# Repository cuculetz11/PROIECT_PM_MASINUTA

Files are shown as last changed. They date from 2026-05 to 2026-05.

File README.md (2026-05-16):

# Land Buster — Autonomous & Multi-Mode Bluetooth Rover

Cucu Viorel-Cosmin 334CA

> **GitHub:** [https://github.com/cuculetz11/PROIECT_PM_MASINUTA](https://github.com/cuculetz11/PROIECT_PM_MASINUTA)  
> **MCU:** ATmega328P Xplained Mini · PlatformIO

---

## Introduction

**Land Buster** is a small RC car (1/12 scale Land Buster chassis) that I upgraded into a smart rover. Instead of using a standard radio remote, I control it from my phone via Bluetooth.

The main idea was simple: a normal RC car does whatever you tell it, even if it is about to crash. I wanted to fix that. So I added sensors and automatic logic on top of the manual control.

**What it does:**
- You drive it with a phone app over Bluetooth. You can pick between 3 speed modes and honk the horn.
- The front ultrasonic sensor watches for obstacles. The buzzer starts beeping faster as you get closer. If you get too close (under 15 cm), the car stops by itself — you cannot override it.
- The headlights turn on automatically when it gets dark, based on a light sensor.
- The LCD screen shows the current speed mode and the distance to the nearest obstacle in real time.

**Why it is useful:** It shows how a cheap microcontroller can handle multiple real-time tasks at once — wireless communication, sensing, motor control, and display — using only hardware registers and no external libraries.

**Course requirements met:**
- **5 laboratory concepts:** USART (Lab 1), Timers & Interrupts (Lab 2), PWM (Lab 3), ADC (Lab 4), I2C (Lab 6)
- **5 external peripherals:** HC-05 Bluetooth, HC-SR04 Ultrasonic, 1602 I2C LCD, Photoresistor, Active Buzzer

---

## General Description

The ATmega328P is the brain of the system. Everything connects to it.

- **Inputs:** Bluetooth commands from the phone, distance data from the ultrasonic sensor, light level from the photoresistor.
- **Processing:** The MCU reads all inputs, decides what to do (drive, stop, beep, light up), and sends signals to the outputs.
- **Outputs:** The ESC drives the main motor (speed), the L298N drives the steering motor (direction), the LCD shows status, the buzzer gives audio alerts, and the LEDs provide lighting.

### Block Diagram

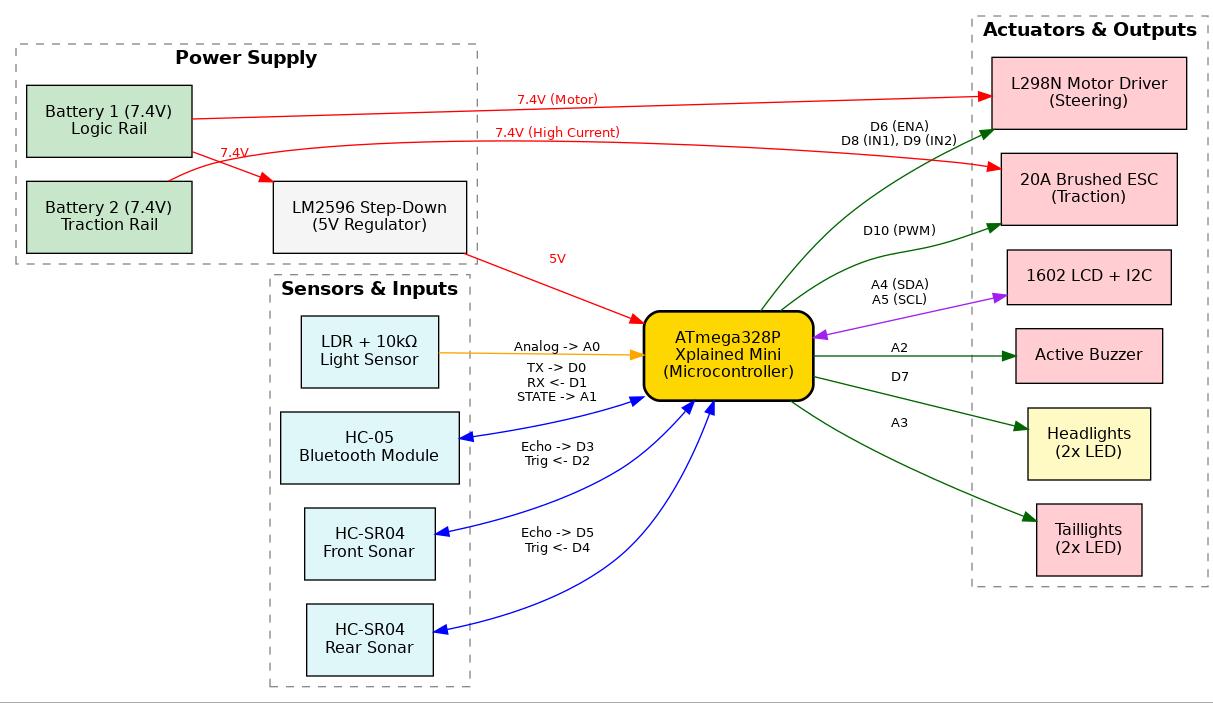
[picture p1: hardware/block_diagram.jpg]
Land Buster System Block Diagram


---

## Hardware Design

### Components and Their Role

| Component | Model | Role in Project |
|---|---|---|
| Microcontroller | ATmega328P Xplained Mini | Central brain. Reads all sensors, runs non-blocking logic, outputs PWM and I2C signals. |
| Bluetooth Module | HC-05 | Bidirectional telemetry with Android app - receives drive commands, sends sensor data. |
| Front Ultrasonic Sensor | HC-SR04 | Measures distance to obstacles ahead. Triggers buzzer alerts and emergency stop at <15 cm. |
| Rear Ultrasonic Sensor | HC-SR04 | Measures distance behind the rover. Powers the reverse parking assist display on the LCD. |
| Light Sensor | GL5528 Photoresistor + 10kΩ | Voltage divider read by ADC. Activates headlights automatically when ambient light drops. |
| Speed Controller | 20A Brushed ESC | Controls the rear 390 DC traction motor via 50 Hz PWM. Receives signal from MCU Timer 1. |
| Traction Motor | 390 DC Motor (7.4V) | Drives the rover forward and backward from Battery 2's dedicated high-current rail. |
| Steering Motor | 3–6V DC Motor | Turns the front axle left or right under L298N control. |
| Motor Driver | L298N H-Bridge | Accepts PWM (ENA) and two direction pins (IN1/IN2) to drive the steering DC motor. |
| LCD Display | 1602 LCD + PCF8574 I2C | "Smart dashboard": shows expressive animated eyes in normal mode, parking assist in reverse. |
| Active Buzzer | TMB12A05 5V | Proximity alert (beep rate increases near obstacles) and horn command from phone. |
| Headlights & Taillights | 5mm LEDs x4 + 220Ω x4 | Front lighting (D7) activates automatically via LDR. Rear taillights (A3) activate on brake/reverse. Wired in parallel. |
| Voltage Regulator | LM2596 Step-Down | Converts Battery 1's 7.4V down to a stable 5V for all logic (MCU, sensors, LCD). |
| Battery 1 - Logic Rail | 2x Murata US18650VTC5C in series | 7.4V, 2600 mAh, 30A. Powers L298N and LM2596 (which feeds 5V logic). |
| Battery 2 - Traction Rail | 2x Samsung 25R 18650 in series | 7.4V, 2500 mAh, 8C. Dedicated high-current supply exclusively for the ESC. |
| Chassis | Land Buster 1/12 scale | Physical base of the rover. |

### Pin Mapping and Justification

| Arduino Pin | AVR Register | Timer / Peripheral | Connected To | Why This Pin |
|---|---|---|---|---|
| D0 (RX) | PD0 | USART0 RX | HC-05 TX | Hardware USART - zero-latency interrupt-driven reception (RXCIE0). No bit-banging needed. |
| D1 (TX) | PD1 | USART0 TX | HC-05 RX via 1kΩ/2kΩ divider | Same USART peripheral. 5V output is divided to 3.3V to protect HC-05 RX logic level. |
| D2 | PD2 | GPIO Output | HC-SR04 Front - TRIG | Any GPIO works for the 10 µs trigger pulse. D2 keeps sensor pins grouped together. |
| D3 | PD3 | GPIO Input | HC-SR04 Front - ECHO | Paired with D2 for clean wiring. Reads echo pulse duration via pulseIn(). |
| D4 | PD4 | GPIO Output | HC-SR04 Rear - TRIG | Same reason as D2; rear sensor pins grouped on D4/D5. |
| D5 | PD5 | GPIO Input | HC-SR04 Rear - ECHO | Paired with D4. Mirrors front sensor logic for parking assist. |
| D6 | PD6 | Timer 0, OC0A (Fast PWM) | L298N ENA | Only OC0A or OC0B can output Timer 0 PWM. D6 = OC0A - sets steering motor duty cycle (0–255). |
| D7 | PD7 | GPIO Output | Headlight LEDs + 220Ω | Simple digital ON/OFF for the LED array. D7 is free from any timer to avoid conflicts. |
| D8 | PB0 | GPIO Output | L298N IN1 | Direction bit for steering H-bridge. No special hardware needed - plain digital output. |
| D9 | PB1 | GPIO Output | L298N IN2 | Direction bit for steering H-bridge (opposite of IN1 to select left/right). |
| D10 | PB2 | Timer 1, OC1B (Phase-correct PWM) | ESC Signal | Timer 1 is 16-bit - essential for generating the precise 50 Hz (20 ms period) servo-style PWM the ESC requires. ICR1=39999, OCR1B range 2600–3400 for speed control. |
| A0 | PC0 | ADC0 | LDR Voltage Divider | First ADC channel; no mux change needed for single-channel reads. Direct analog measurement of light level. |
| A1 | PC1 | GPIO Input | HC-05 STATE | Reads hardware connection status (HIGH = connected, LOW = disconnected/searching). |
| A2 | PC2 | GPIO Output | Active Buzzer | Moved here from SPI pins to keep PB3/PB4/PB5 free for the Xplained Mini's programming interface (EDBG). |
| A3 | PC3 | GPIO Output | Rear LED Taillights | Dedicated pin for red rear taillights. Activates independently during AEB, reverse, or stop. |
| A4 | PC4 | TWI SDA (Hardware I2C) | LCD PCF8574 SDA | Hardware I2C peripheral - only PC4/PC5 support hardware TWI on ATmega328P. |
| A5 | PC5 | TWI SCL (Hardware I2C) | LCD PCF8574 SCL | Paired with A4. Hardware TWI runs at 100 kHz without CPU intervention. |

**Note — SPI pins reserved:** PB3 (MOSI), PB4 (MISO), PB5 (SCK) are left unconnected. These are used internally by the Xplained Mini's on-board EDBG debugger for programming. Connecting peripherals to them would block firmware uploads.

### Key Design Choices & Electrical Schematic

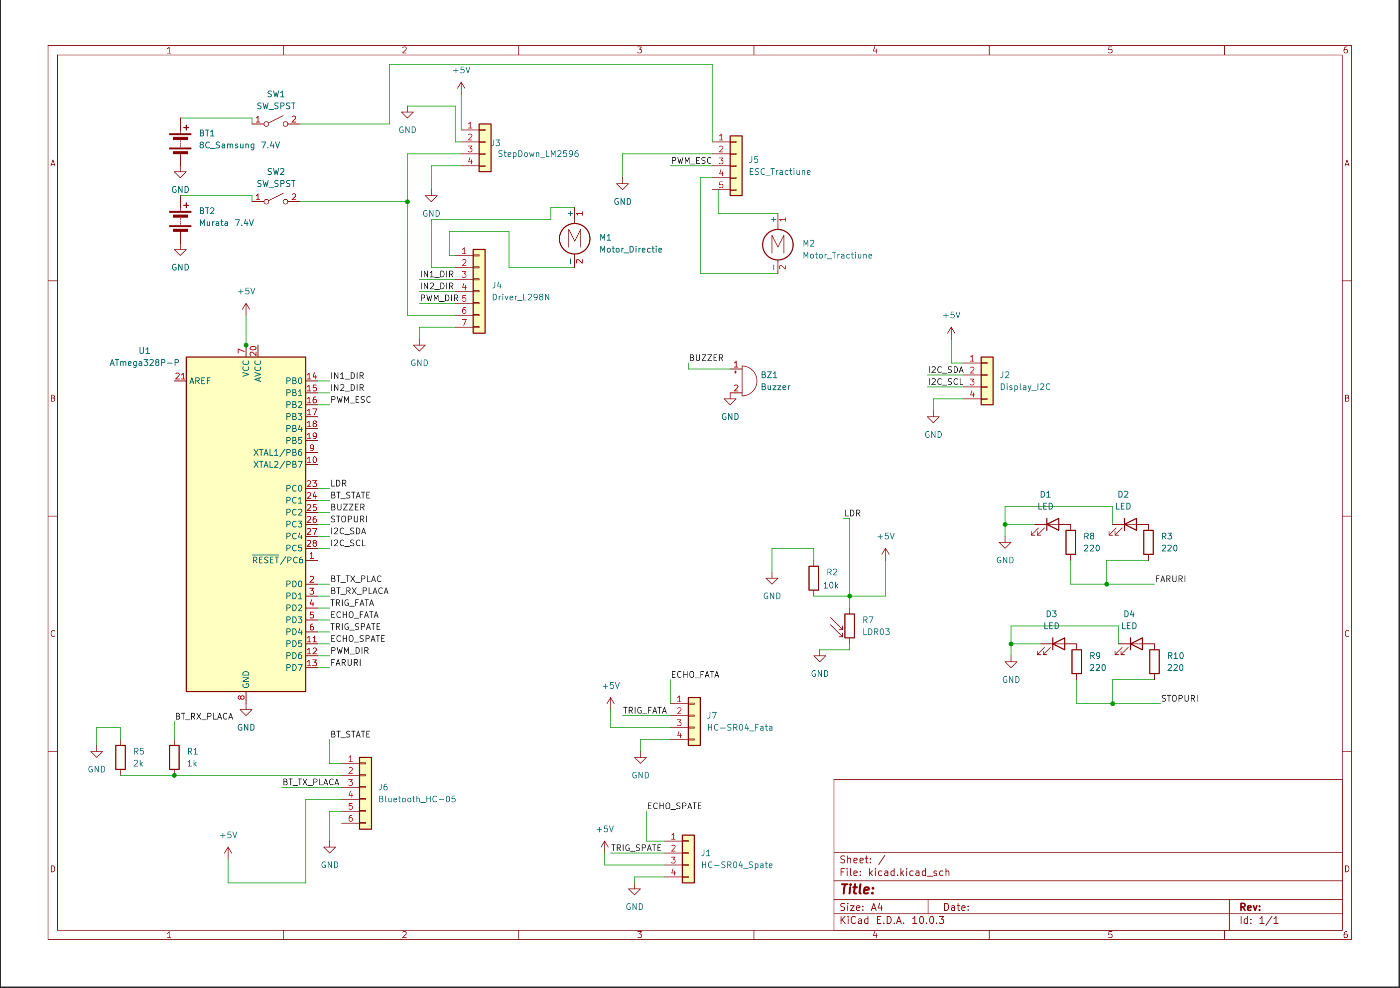
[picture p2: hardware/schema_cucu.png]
Land Buster Electrical Schematic


The electrical schematic above illustrates the complete wiring of the Land Buster rover. The hardware architecture is built upon the following core engineering rules:

* **Dual Isolated Power System:** The system utilizes two separate battery packs. Battery 1 (Logic Rail) powers the L298N and the LM2596 regulator, which supplies a clean 5V to the MCU, sensors, and LCD. Battery 2 (Traction Rail) is dedicated exclusively to the high-current ESC. This isolation prevents massive voltage drops caused by the main motor from resetting the microcontroller.
* **Common Ground:** Despite having two isolated power sources, all ground (GND) connections across the entire system are tied together. This sets a unified 0V reference point, ensuring that PWM and digital logic signals are accurately interpreted by every component.
* **LED Parallel Wiring:** To ensure maximum brightness and protect the MCU pins, all 4 LEDs (2 front, 2 rear) are wired in parallel. Each LED connects to its respective MCU pin (D7 or A3) through its own dedicated 220Ω current-limiting resistor before returning to the common ground.
* **HC-05 Level Shifting:** The Bluetooth module operates at 3.3V logic. To prevent hardware damage, a simple voltage divider (1kΩ in series from MCU D1, then 2kΩ to GND) safely steps down the 5V USART TX signal to ≈3.3V before it reaches the module.
* **Timer Selection Strategy:** Timer 0 (8-bit) is used for the low-resolution steering PWM (Fast PWM, ~980 Hz). Timer 1 (16-bit) is strictly reserved for the ESC because it requires a precise 50 Hz period, which is impossible to achieve accurately with only 8 bits.

### Proof of Functionality & Assembly

**Photo 1: Power Drop Test**

Power Drop Test

This early prototype test was conducted with only the steering system and ESC connected. While running the main traction motor at a low RPM, the output of the LM2596 regulator dropped dangerously to 4.7V. This critical observation proved that a single battery configuration was insufficient to handle the high current spikes, directly justifying the upgrade to the current dual-battery (4-cell) isolated power system.

**Photo 2: Full System Test**

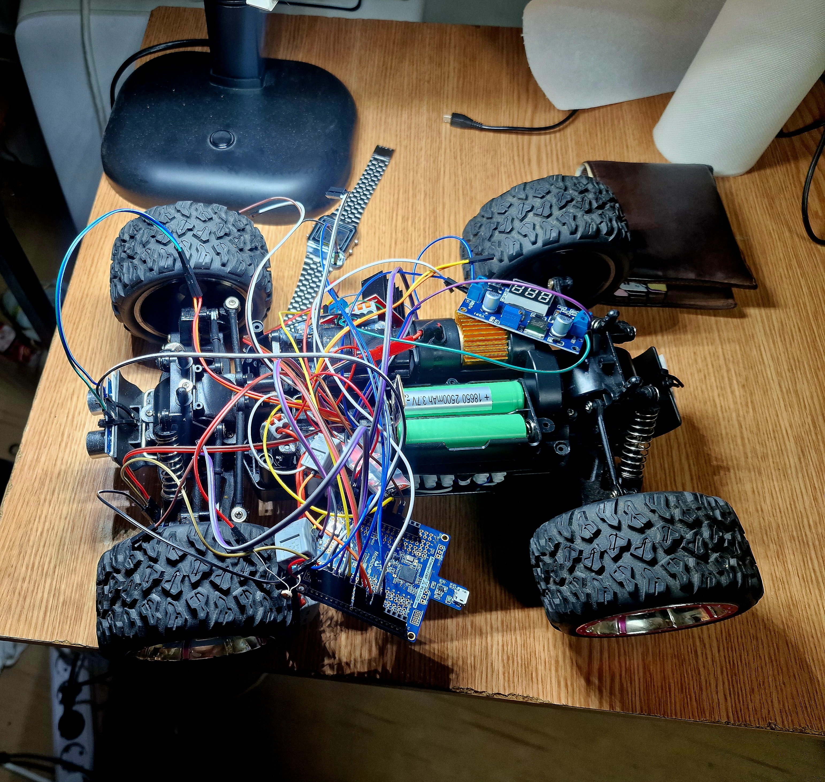
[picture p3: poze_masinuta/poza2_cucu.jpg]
Full System Test


All electronic components—including the ultrasonic sensors, I2C LCD, HC-05 Bluetooth module, and motor drivers—are integrated and tested together. This phase successfully verified the software integration, ensuring that the non-blocking logic, telemetry, and autonomous emergency braking (AEB) functioned simultaneously without interference, proving the system's core functionality.

**Photo 3: Clean Build**

Clean Build

The final hardware assembly mounted on the Land Buster chassis. This image highlights the strict cable management and the custom mechanical modifications made to the chassis to accommodate all the new components. To ensure maximum stability, the electronics and wiring were permanently secured using high-strength adhesives (epoxy resin and cyanoacrylate).

**Photo 4: Final Assembly**

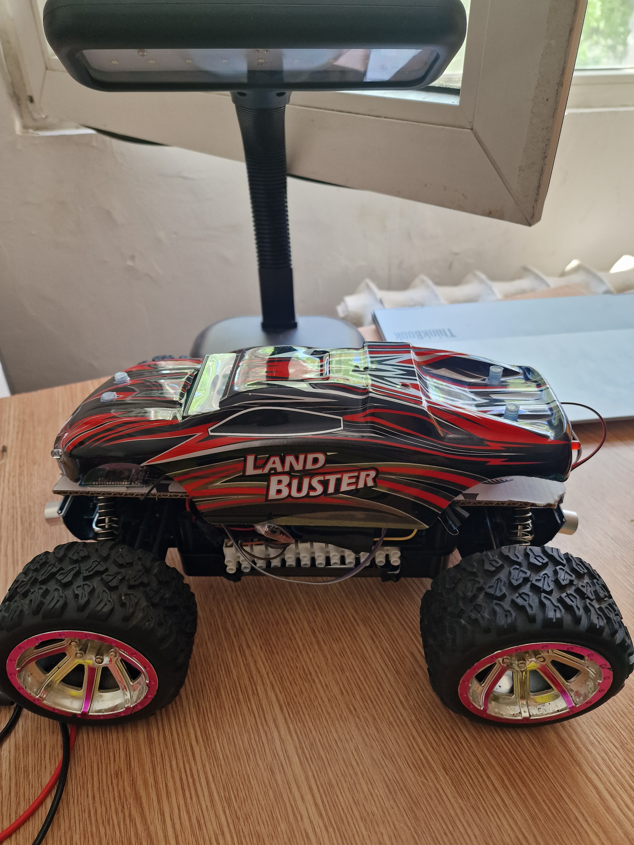
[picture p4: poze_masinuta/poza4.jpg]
Final Assembly


The completed autonomous rover with the original outer car shell successfully mounted.

---

## Software Design

### Development Environment

- **IDE:** PlatformIO (VS Code)
- **Language:** Pure AVR C — all peripherals are controlled via direct register writes. No Arduino libraries.
- **Compiler:** avr-gcc
- **Target:** ATmega328P Xplained Mini

### Source Files

```
src/
├── main.c          # Main loop, ISR, command dispatcher
├── usart.c / .h    # USART driver + printf via stdout (Lab 1)
├── ultrasonic.c    # HC-SR04 distance measurement (Lab 2)
├── motor.c         # PWM steering control via L298N (Lab 3)
├── adc.c / .h      # ADC driver for photoresistor (Lab 4)
└── task1.c         # ADC read + threshold logic (tested standalone)
```

### Lab 1 — USART: Bluetooth Control

The HC-05 sends bytes from the phone app at 9600 baud. The **RX Complete Interrupt (RXCIE0)** fires automatically when a byte arrives.

```c
// usart.c
void USART0_init(unsigned int ubrr) {
    UBRR0H = (unsigned char)(ubrr >> 8);
    UBRR0L = (unsigned char)ubrr;
    UCSR0B = (1 << RXEN0) | (1 << TXEN0) | (1 << RXCIE0);
    UCSR0C = (1 << USBS0) | (3 << UCSZ00); // 8-bit, 2 stop bits
}
```

```c
// main.c — ISR
volatile char comanda_bt = 0;

ISR(USART_RX_vect) {
    char c = UDR0;
    if (c != '\r' && c != '\n') comanda_bt = c;
}
```

Commands: `F` Forward, `B` Backward, `L` Left, `R` Right, `S` Stop, `H` Horn, `1`/`2`/`3` Speed mode.

### Lab 2 — Timers: Ultrasonic Distance

**Timer 1** measures the HC-SR04 echo pulse. At 16MHz prescaler 8, one tick = 0.5µs → `distance_cm = ticks / 116`.

```c
// ultrasonic.c
uint16_t get_distance() {
    PORTD &= ~(1 << PD2); _delay_us(2);
    PORTD |=  (1 << PD2); _delay_us(10);
    PORTD &= ~(1 << PD2);

    uint32_t counter = 0;
    while (!(PIND & (1 << PD4))) {
        if (++counter > 100000) return 0;
    }

    TCNT1 = 0;
    TCCR1B = (1 << CS11);
    while (PIND & (1 << PD4)) {
        if (TCNT1 > 40000) break;
    }
    TCCR1B = 0;
    return TCNT1 / 116;
}
```

### Lab 3 — PWM: Steering Control

**Timer 0** in Fast PWM mode on OC0A (PD6). `OCR0A` sets duty cycle (0–255). `PB0`/`PB1` select direction.

```c
// motor.c
void motor_steering_init() {
    DDRD |= (1 << PD6);
    DDRB |= (1 << PB0) | (1 << PB1);
    TCCR0A = (1 << COM0A1) | (1 << WGM01) | (1 << WGM00);
    TCCR0B = (1 << CS01) | (1 << CS00); // prescaler 64
    OCR0A = 0;
}

void motor_steer(int direction, uint8_t power) {
    OCR0A = power;
    if (direction == 1)       { PORTB |=  (1<<PB0); PORTB &= ~(1<<PB1); }
    else if (direction == -1) { PORTB &= ~(1<<PB0); PORTB |=  (1<<PB1); }
    else                      { PORTB &= ~(1<<PB0); PORTB &= ~(1<<PB1); }
}
```

### Lab 4 — ADC: Automatic Headlights

Photoresistor on **PC0 (ADC0)** in voltage divider. When dark → LEDs turn on automatically.

```c
// adc.c
void adc_init() {
    ADCSRA = (1 << ADEN) | (7 << ADPS0); // prescaler 128
    ADMUX  = (1 << REFS0);               // AVcc reference
}

uint16_t myAnalogRead(uint8_t channel) {
    ADMUX &= 0b11100000;
    ADMUX |= (channel & 0b00000111);
    ADCSRA |= (1 << ADSC);
    while (ADCSRA & (1 << ADSC));
    return ADC;
}
```

### Lab 6 — I2C: LCD Telemetry

> 🔄 **In progress.** TWI hardware used at 100kHz. Registers: `TWBR`, `TWSR`, `TWCR`, `TWDR`. LCD will show speed mode and distance.

### Hypothesis

> *"Using hardware interrupts for Bluetooth and hardware timers for distance will keep response time under 100ms — even while the LCD is updating."*

### Metrics & Targets
VEDEM

| What | Target | How |
|---|---|---|
| Command response time | < 100 ms | Oscilloscope: BT RX → PWM change |
| Distance accuracy | ±1 cm | Compare to ruler |
| Emergency brake | 100% at ≤ 15 cm | 20 test runs |
| LCD update rate | ≥ 5 Hz | Count I2C calls/second |
| Headlight response | < 200 ms | Cover/uncover sensor, time LED toggle |

### Novelty

1. **Collision prevention:** Progressive buzzer + automatic emergency brake at 15cm.
2. **Adaptive lighting:** Headlights react to environment automatically.

**Planned extra:** Rear HC-SR04 for reverse parking assist.

---

## Expected Results

| Feature | Status |
|---|---|
| Bluetooth command reception | Tested |
| ADC light reading | Tested |
| Ultrasonic distance | Tested |
| PWM steering (L298N) | In progress |
| Speed modes via ESC | In progress |
| Progressive buzzer | In progress |
| Emergency brake at 15cm | In progress |
| I2C LCD telemetry | In progress |
| Automatic headlights | In progress |

---

## Conclusions

This project shows that one small 8-bit microcontroller can handle wireless control, sensing, motor driving, and display — all at once — using only hardware registers.

Key lessons:
- **Interrupts** keep Bluetooth reception reliable without blocking the main loop.
- **Hardware timers** give accurate distance measurement.
- **Separate power rails** protect the MCU from motor noise and voltage drops.

---

## Journal

```
Task                              W1  W2  W3  W4  W5  W6  W7  W8  W9
──────────────────────────────────────────────────────────────────────
Planning & chassis setup          xxx xxx
Validate USART, ADC, Ultrasonic           xxx xxx
PWM speed & steering control                      xxx xxx
I2C LCD + emergency brake logic                           xxx xxx
Final assembly & testing                                          xxx
```

| Phase | Weeks | Goal |
|---|---|---|
| Planning & chassis setup | W1–W2 | Component list, schematic, chassis |
| Validate peripherals | W3–W4 | USART, ADC, Ultrasonic confirmed working |
| PWM control | W5–W6 | 3 speed modes, steering working |
| I2C & safety logic | W7–W8 | LCD + emergency brake at 15cm |
| Final assembly | W9 | Clean wiring, all metrics measured |

---

## Bibliography / Resources

### Hardware Datasheets

| Component | Source |
|---|---|
| ATmega328P Datasheet | [Microchip Technology](https://ww1.microchip.com/downloads/en/DeviceDoc/Atmel-7810-Automotive-Microcontrollers-ATmega328P_Datasheet.pdf) |
| HC-SR04 Ultrasonic Sensor | [Components101](https://components101.com/ultrasonic-sensor-working-pinout-datasheet) |
| LM2596 Step-Down Regulator | [Texas Instruments](https://www.ti.com/product/LM2596) |
| PCF8574 I2C Expander | [Texas Instruments](https://www.ti.com/product/PCF8574) |
| HC-05 Bluetooth Module | Vendor documentation |
| GL5528 Photoresistor | Manufacturer datasheet |
| L298N H-Bridge | STMicroelectronics datasheet |

### Tools

| Tool | Used For |
|---|---|
| PlatformIO + VS Code | Writing and uploading firmware |
| avr-gcc + avr-size | Compiling and checking memory |
| Serial Bluetooth Terminal (Android) | Sending commands from phone |

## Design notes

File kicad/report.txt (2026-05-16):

Plotted to '/home/cuculet/Documents/pm/PROIECT_PDF/proeict_masina/kicad/kicad.pdf'.

Info: Done.

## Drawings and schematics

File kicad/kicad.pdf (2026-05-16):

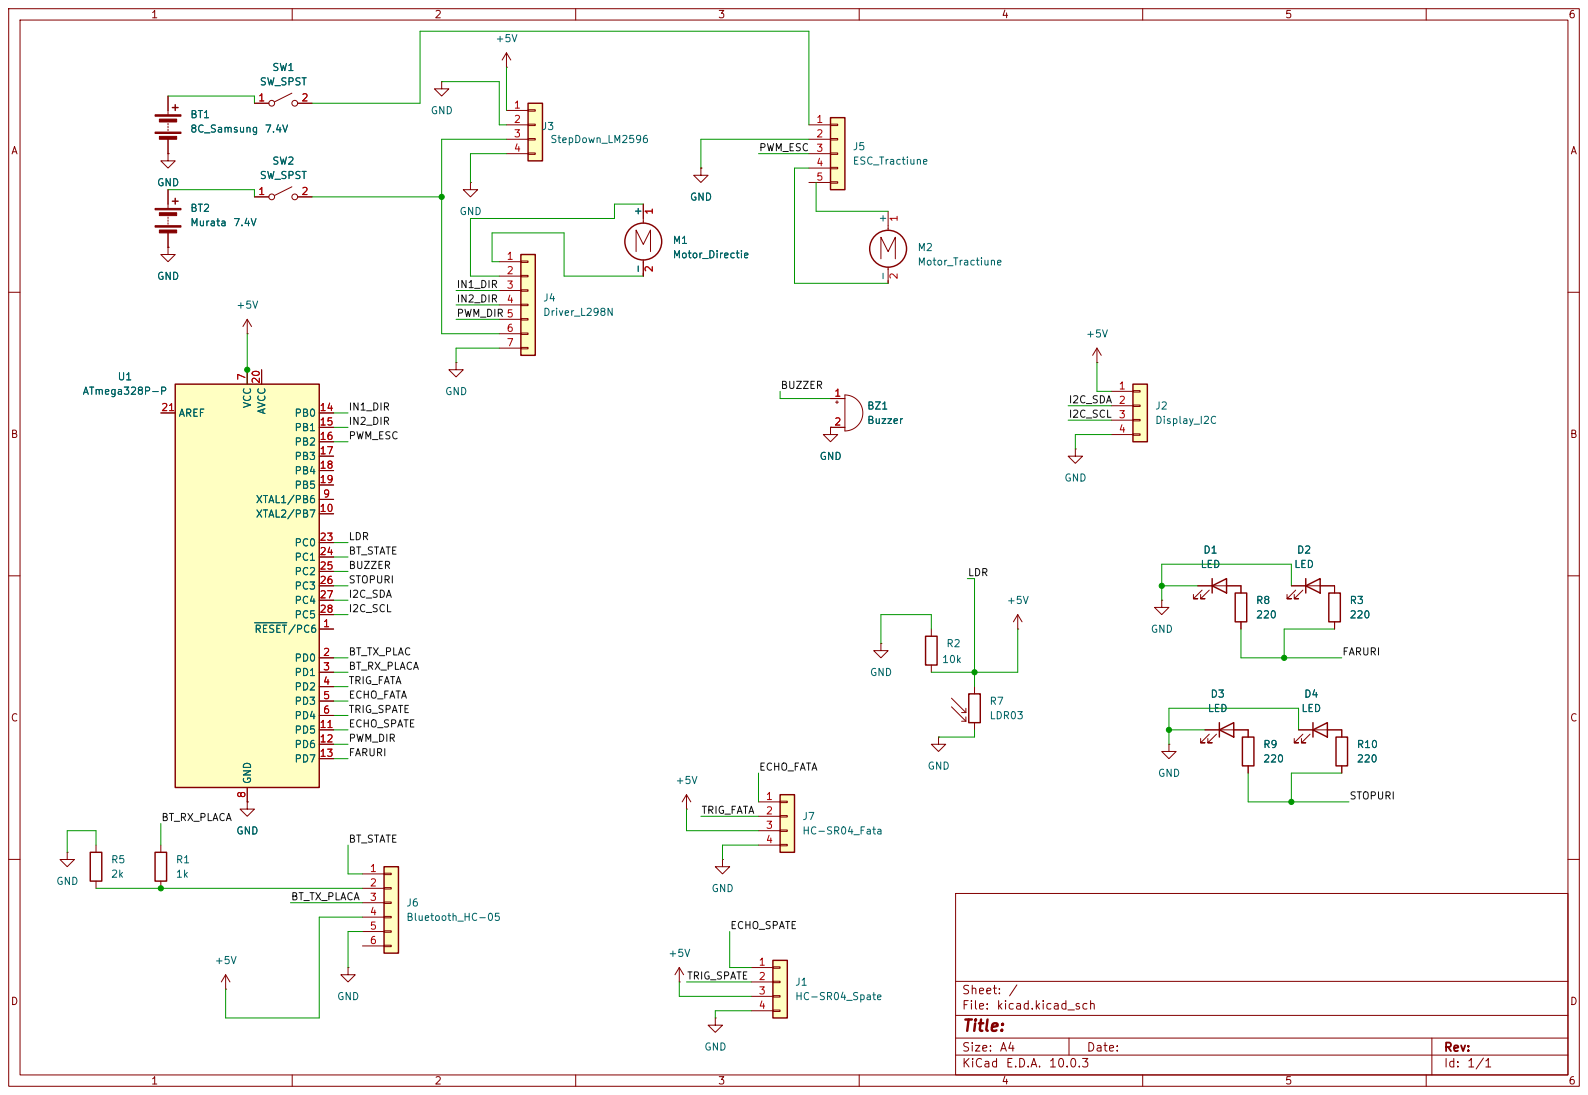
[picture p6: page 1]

Size: A4 | Rev:
KiCad E.D.A. 10.0.3 | Id: 1/1

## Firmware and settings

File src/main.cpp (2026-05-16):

#include <Arduino.h>
#include <Wire.h>
#include <LiquidCrystal_I2C.h>

// --- PINI ---
#define TRIG_FATA 2
#define ECHO_FATA 3
#define TRIG_SPATE 4
#define ECHO_SPATE 5
#define LED_FATA 7
#define LED_SPATE A3  // NOU: Pinul PC3 pentru stopurile rosii din spate

#define IN1 8   // PB0
#define IN2 9   // PB1
#define ENA 6   // PD6
#define PIN_ESC 10 // PB2

#define BUZZER A2
#define PIN_LDR A0
#define PIN_STATE A1 // NOU: Starea conexiunii HC-05

// --- GRAFICA CUSTOM LCD ---
byte eye[8]         = { B01000, B00100, B00110, B00110, B01111, B01111, B11111, B01110 };
byte blinked_eye[8] = { B00000, B00000, B00000, B00000, B00000, B11111, B00110, B00000 };
byte ebrow_1[8]     = { B00000, B00000, B00000, B00000, B00001, B00010, B00100, B00000 };
byte ebrow_2[8]     = { B00000, B00000, B01110, B10001, B00000, B00000, B00000, B00000 };
byte ebrow_3[8]     = { B00000, B00000, B00000, B00000, B10000, B01000, B00100, B00000 };
byte arrowAnim[8]   = { B00010, B00110, B01110, B11110, B01110, B00110, B00010, B00000 };

LiquidCrystal_I2C lcd(0x27, 16, 2);

// --- VARIABILE DE STARE ---
unsigned long last_cmd_millis = 0;
bool failsafe_active = true;

char motor_dir = 'c';   // w, x, c
char motor_steer = 'a'; // a, s, d
int gear = 1;           // 1, 2, 3, 4 (turbo)
int headlight_mode = 0; // 0=auto, 1=on, 2=off

unsigned long horn_end_time = 0;

int ultimul_mood = -1;
bool ultima_clipire = false;
char ultimul_steer = 'a';
unsigned long timp_urmat_clipire = 0;
bool ochi_inchisi = false;

uint16_t timer_serial = 0;
uint16_t frame_sageata = 0;
unsigned long last_marsarier_anim = 0;
unsigned long last_deconectat_anim = 0;

unsigned long last_buzzer_toggle = 0;
bool buzzer_state = false;
unsigned long last_telemetry_time = 0;

// --- FUNCTII ---
long get_dist(uint8_t trig, uint8_t echo) {
    digitalWrite(trig, LOW); delayMicroseconds(2);
    digitalWrite(trig, HIGH); delayMicroseconds(10);
    digitalWrite(trig, LOW);
    long duration = pulseIn(echo, HIGH, 20000); 
    if (duration == 0) return 999;
    return duration / 58;
}

void pwm_init() {
    pinMode(PIN_ESC, OUTPUT);
    // Fast PWM 10-bit pentru Timer 1
    TCCR1A = (1 << COM1B1) | (1 << WGM11);
    TCCR1B = (1 << WGM13) | (1 << WGM12) | (1 << CS11);
    ICR1 = 39999; 
    OCR1B = 3000; 

    pinMode(ENA, OUTPUT);
    TCCR0A = (1 << COM0A1) | (1 << WGM01) | (1 << WGM00);
    TCCR0B = (1 << CS01);
    OCR0A = 0; 
}

void setup() {
    Serial.begin(9600);
    
    pinMode(TRIG_FATA, OUTPUT); pinMode(ECHO_FATA, INPUT);
    pinMode(TRIG_SPATE, OUTPUT); pinMode(ECHO_SPATE, INPUT);
    pinMode(IN1, OUTPUT); pinMode(IN2, OUTPUT);
    pinMode(LED_FATA, OUTPUT); pinMode(BUZZER, OUTPUT);
    pinMode(LED_SPATE, OUTPUT); // Initializare stopuri
    pinMode(PIN_STATE, INPUT);
    pinMode(PIN_LDR, INPUT);
    
    pwm_init();

    lcd.init();
    lcd.backlight();
    
    lcd.createChar(0, eye);
    lcd.createChar(1, blinked_eye);
    lcd.createChar(2, ebrow_1);
    lcd.createChar(3, ebrow_2);
    lcd.createChar(4, ebrow_3);
    lcd.createChar(5, arrowAnim);

    lcd.setCursor(0, 0); lcd.print(" Initializare...");
    delay(5000); // Wait for ESC arming
    lcd.clear();
}

void loop() {
    unsigned long timp_curent = millis();
    bool bt_connected = digitalRead(PIN_STATE) == HIGH;

    // ==========================================
    // 1. BLUETOOTH & PARSER
    // ==========================================
    if (Serial.available()) {
        char c = Serial.read();
        if (c == 'w' || c == 's' || c == 'd' || c == 'a' || c == 'x' || c == 'c' || 
            c == '1' || c == '2' || c == '3' || c == 't' || c == 'l' || c == 'h') {
            
            last_cmd_millis = timp_curent;
            failsafe_active = false;
            
            switch(c) {
                case 'w': motor_dir = 'w'; break;
                case 'x': motor_dir = 'x'; break;
                case 'c': motor_dir = 'c'; break;
                case 's': motor_steer = 's'; break;
                case 'd': motor_steer = 'd'; break;
                case 'a': motor_steer = 'a'; break;
                case '1': gear = 1; break;
                case '2': gear = 2; break;
                case '3': gear = 3; break;
                case 't': gear = 4; break;
                case 'l': headlight_mode = (headlight_mode + 1) % 3; break;
                case 'h': horn_end_time = timp_curent + 500; break;
            }
        }
    }

    // ==========================================
    // 2. FAILSAFE (WATCHDOG)
    // ==========================================
    if (timp_curent - last_cmd_millis > 500) {
        motor_dir = 'c';
        motor_steer = 'a';
        failsafe_active = true;
    }

    // ==========================================
    // 3. SENZORI & FARURI (LDR)
    // ==========================================
    long df = get_dist(TRIG_FATA, ECHO_FATA);
    long ds = get_dist(TRIG_SPATE, ECHO_SPATE);
    int lumina = analogRead(PIN_LDR);

    if (headlight_mode == 1) {
        digitalWrite(LED_FATA, HIGH);
    } else if (headlight_mode == 2) {
        digitalWrite(LED_FATA, LOW);
    } else { // Auto
        digitalWrite(LED_FATA, lumina < 400 ? HIGH : LOW);
    }

    // ==========================================
    // 4. AEB (Autonomous Emergency Braking)
    // ==========================================
    bool aeb_fata = (df < 10);
    bool aeb_spate = (ds < 10);

    if (aeb_fata && motor_dir == 'w') motor_dir = 'c'; // Ignoram acceleratia spre obstacol fata
    if (aeb_spate && motor_dir == 'x') motor_dir = 'c'; // Ignoram acceleratia spre obstacol spate

    // ==========================================
    // 4.5 STOPURI (Sistem inteligent de frana / marsarier)
    // ==========================================
    // Stopurile se aprind DACA: masina e pe loc ('c'), da cu spatele ('x') SAU a intrat frana automata (AEB)
    if (motor_dir == 'c' || motor_dir == 'x' || aeb_fata || aeb_spate) {
        digitalWrite(LED_SPATE, HIGH);
    } else {
        // Se sting cand masina merge inainte normal ('w')
        digitalWrite(LED_SPATE, LOW);
    }

    // ==========================================
    // 5. BUZZER (Prioritate: Claxon > AEB > Parcare)
    // ==========================================
    long min_dist = min(df, ds);
    bool horn_active = (timp_curent < horn_end_time);

    if (horn_active) {
        digitalWrite(BUZZER, HIGH);
    } else if (aeb_fata || aeb_spate) {
        digitalWrite(BUZZER, HIGH); // Continuu pt urgenta
    } else {
        // Senzor parcare progresiv
        if (min_dist > 40) {
            digitalWrite(BUZZER, LOW);
        } else {
            int interval = 0;
            if (min_dist > 25) interval = 600; // Rar
            else if (min_dist >= 10) interval = 200; // Des
            
            if (timp_curent - last_buzzer_toggle >= interval) {
                buzzer_state = !buzzer_state;
                digitalWrite(BUZZER, buzzer_state ? HIGH : LOW);
                last_buzzer_toggle = timp_curent;
            }
        }
    }

    // ==========================================
    // 6. MOTOARE (Tractiune & Directie)
    // ==========================================
    // Directie (Timer 0)
    if (motor_steer == 'a') {
        digitalWrite(IN1, LOW); digitalWrite(IN2, LOW); OCR0A = 0;
    } else if (motor_steer == 's') {
        digitalWrite(IN1, HIGH); digitalWrite(IN2, LOW); OCR0A = 255;
    } else if (motor_steer == 'd') {
        digitalWrite(IN1, LOW); digitalWrite(IN2, HIGH); OCR0A = 255;
    }

    // Tractiune (Timer 1)
    if (motor_dir == 'c') {
        OCR1B = 3000;
    } else if (motor_dir == 'x') {
        OCR1B = 2600; // Marsarier fix
    } else if (motor_dir == 'w') {
        if (gear == 1) OCR1B = 3100;
        else if (gear == 2) OCR1B = 3200;
        else if (gear == 3) OCR1B = 3300;
        else if (gear == 4) OCR1B = 3400; // Turbo
    }

    // ==========================================
    // 7. ANIMATII I2C LCD (Non-blocking & Flicker-free)
    // ==========================================
    int mood = 0; // 0=Ochi normali, 1=Angry/Stop (AEB), 2=Marsarier (Senzor parcare), 3=Deconectat
    if (!bt_connected) mood = 3;
    else if (aeb_fata || aeb_spate) mood = 1;
    else if (motor_dir == 'x') mood = 2;

    // Logica de clipire aleatorie
    if (!ochi_inchisi && timp_curent > timp_urmat_clipire) {
        ochi_inchisi = true;
        timp_urmat_clipire = timp_curent + 150; 
    } else if (ochi_inchisi && timp_curent > timp_urmat_clipire) {
        ochi_inchisi = false;
        timp_urmat_clipire = timp_curent + random(2000, 5000); 
    }

    bool act_marsarier = (mood == 2 && timp_curent - last_marsarier_anim >= 250);
    bool act_deconectat = (mood == 3 && timp_curent - last_deconectat_anim >= 500);

    // Actualizare ecran
    if (mood != ultimul_mood || ochi_inchisi != ultima_clipire || motor_steer != ultimul_steer || act_marsarier || act_deconectat) {
        
        if (mood != ultimul_mood) {
            lcd.clear(); // Evitam flickerul, dam clear DOAR la tranzitia de stare
        }

        if (mood == 3) {
            // Deconectat
            if (mood != ultimul_mood || act_deconectat) {
                lcd.setCursor(0, 0); lcd.print("Caut conexiune  ");
                lcd.setCursor(0, 1); 
                int puncte = (timp_curent / 500) % 4; // Animatie 0-3 puncte
                for(int i=0; i<3; i++) {
                    if (i < puncte) lcd.print("."); else lcd.print(" ");
                }
                last_deconectat_anim = timp_curent;
            }
        } 
        else if (mood == 2) { 
            // Marsarier
            if (mood != ultimul_mood || act_marsarier) {
                lcd.setCursor(0, 0); lcd.print(" [R] MARSARIER  ");
                lcd.setCursor(0, 1); lcd.print(" Dist: "); 
                if(ds == 999) lcd.print("Liber  "); else { lcd.print(ds); lcd.print("cm   "); }
                
                // Animatie sageata
                if(frame_sageata % 2 == 0) { lcd.setCursor(14, 1); lcd.write(5); lcd.print(" "); }
                else { lcd.setCursor(14, 1); lcd.print(" "); lcd.write(5); }
                frame_sageata++;
                last_marsarier_anim = timp_curent;
            }
        } 
        else {
            // Ochi Animati
            if (mood != ultimul_mood || ochi_inchisi != ultima_clipire || motor_steer != ultimul_steer) {
                int pos_left_eye = 3;
                int pos_right_eye = 12;
                // Deplasare privire in functie de directie
                if (motor_steer == 's') { pos_left_eye = 2; pos_right_eye = 11; }
                else if (motor_steer == 'd') { pos_left_eye = 4; pos_right_eye = 13; }

                lcd.setCursor(0, 1); lcd.print("                "); // Curatam doar randul 1
                lcd.setCursor(pos_left_eye, 1); lcd.write(ochi_inchisi ? 1 : 0);
                lcd.setCursor(pos_right_eye, 1); lcd.write(ochi_inchisi ? 1 : 0);

                if (mood == 0) { 
                    lcd.setCursor(0, 0); lcd.print("                "); // Curatam randul 0 pentru sprancene normale
                    lcd.setCursor(pos_left_eye-1, 0); lcd.write(2); lcd.write(3); lcd.write(4);
                    lcd.setCursor(pos_right_eye-1, 0); lcd.write(2); lcd.write(3); lcd.write(4);
                } else if (mood == 1) { 
                    lcd.setCursor(0, 0); lcd.print("                "); // Curatam randul 0 pentru sprancene agresive
                    lcd.setCursor(pos_left_eye-1, 0); lcd.print(" "); lcd.write(3); lcd.write(4);
                    lcd.setCursor(pos_right_eye-1, 0); lcd.write(2); lcd.write(3); lcd.print(" ");
                    lcd.setCursor(6, 1); lcd.print("STOP");
                }
            }
        }

        ultimul_mood = mood;
        ultima_clipire = ochi_inchisi;
        ultimul_steer = motor_steer;
    }

    // ==========================================
    // 8. TELEMETRIE (Catre Android)
    // ==========================================
    if (timp_curent - last_telemetry_time >= 200) {
        char buf[30];
        sprintf(buf, "F:%ld S:%ld\n", df, ds);
        Serial.print(buf);
        last_telemetry_time = timp_curent;
    }

    delay(20); // Bucla ruleaza la max ~25 cadre/sec
}
